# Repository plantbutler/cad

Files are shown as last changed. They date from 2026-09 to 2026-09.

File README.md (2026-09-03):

# plantbutler / cad

Everything physical about Plant Butler, reproducible from source: OpenSCAD parts, the KiCad
wiring diagram, the bill of materials and the bench notes.

- [`manifold/`](manifold/README.md) — the watering manifold: a lead screw moves a magnet cart
  over five ball gates on O-ring seats. Parametric OpenSCAD, ten printed parts, `make stl` for
  the print files. The FreeCAD design it replaces is kept in `manifold/reference/`.
- [`wiring/`](wiring/README.md) — how the bench is wired: four drawings (overview, pump
  switching, sensor bus, power), the pin map with connectors and wire colours, the parts to
  verify, and the bring-up order. Generated from `wiring/nets.py` by `make -C wiring`.

What comes next and in which order is in the [plan](https://github.com/plantbutler/plan); the
decisions it is built on are in the
[umbrella](https://github.com/plantbutler/plantbutler/blob/main/DECISIONS.md).

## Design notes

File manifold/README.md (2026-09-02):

# Plant Butler manifold v3

A parametric OpenSCAD (2021.01) model of the watering manifold: one water gallery with
`n_gates` outlets, each closed by an 8 mm steel ball resting on an O-ring, opened by a magnet
that a lead screw parks over the gate. It is a rebuild of the FreeCAD assembly `valveV2`
(`reference/`) with the inverted-nail plungers replaced by ball gates, every dimension derived
from `params.scad`, and every part printable flat with no supports.

Water enters through the inlet barb at the back, fills the gallery and leaves only through a
gate whose ball is lifted. A cart rides on the lid top, pushed along the manifold by an M3
threaded rod through a nut trapped in one of its ears; the rod turns in the servo holder at
the front and the screw holder at the back, driven by an SG90 through two spur gears outboard
of the servo holder. The magnet in the cart floor rides on the lid: parked over a gate it
lifts that ball off its O-ring and water flows under the ball into the outlet barb. The pump
is off while the cart moves (firmware). Home is the cart resting on the threadless front of
the rod against a spring.

Printed parts: `main_body`, `lid`, `outlet_barb` (one per gate), `end_cap`, `inlet_cap`,
`servo_holder`, `screw_holder`, `cart`, `servo_gear`, `screw_gear`. Hardware: 440C balls,
O-rings, a ø6×3 magnet, an M3 threaded rod, M3 nuts and washers, an SG90, M2 screws, a small
compression spring.

## Frame

X across the width (0..`W`), Y up (0 = outside floor of the main body), Z along the manifold;
the servo end is the front (−Z), the inlet end the back (+Z). Gate `i` (0-based) is centred at
`gate_z(i) = i·pitch + gate_len/2` — 9, 31, 53, 75, 97 with the defaults. Every part module
builds its part in this frame; `<part>_print()` lays it on z = 0 for export;
`<part>_size()` returns its [x, y, z] extents. `assembly.scad` only turns the whole scene by
`screen_rot` for the screen, so Y is up in the pictures.

## How a gate works

The ball (ø `ball_d`) rests on an O-ring of inner diameter `oring_id` and cross-section
`oring_cs`, whose tube centre-line has radius `r_o = (oring_id + oring_cs)/2`; ball and tube
touch when their centres are `Rb = ball_d/2 + oring_cs/2` apart, so the seated ball centre sits
`sqrt(Rb² − r_o²)` above the ring's centre plane `y_ring`. Lifting the ball opens a
frustum-shaped throat between the ring and the ball, of area `π·r_o·(1 + k/D)·(D − Rb)` with
`k = ball_d/2 − oring_cs/2` and `D` the new centre distance; setting that equal to
`lift_factor` × the outlet bore area gives a quadratic in `D`, `lift` follows from it, and the
gallery height `inner_h` is the smallest number of layers that lets the lifted ball touch the
lid lip.

The O-ring sits in a counterbore ø `groove_od` × `groove_d` in the top of a seat boss on the
floor, its inner diameter at the edge of the outlet hole; the counterbore is `groove_d` deep so
the ball touches rubber, never the step. A cage tube on the lid (ø `cage_bore` inside) reaches
`cage_below_equator` below the seated ball's centre, so the ball cannot leave its seat sideways,
and stops `cage_window_h` above the boss so water can enter under it.

## Parameters (`params.scad`)

Everything else is derived; the derivations are guarded by asserts that fail with a message.

| name | default | why |
|---|---|---|
| `line_w`, `layer_h` | 0.4, 0.2 | printer: thin frames are multiples of `line_w`, heights that must land on a layer round up to `layer_h` |
| `fn_round`, `fn_small` | 64, 32 | `$fn` for sealing/running features and for small holes |
| `n_gates` | 5 | outputs |
| `gate_len`, `joint_len` | 18, 4 | gallery length per gate; lap joint length [v2] |
| `wall` | 1.6 | every wall = 4 perimeters; lap joints split it into two half-skins |
| `inner_w` | 18 | gallery width [v2] |
| `extra_len` | 10 | end cap cavity in front of the first gate, room for the water to turn [v2] |
| `joint_clear` | 0.15 | per-side clearance on lap joints and the lid lip (v2 had 0: does not fit FDM) |
| `lip_chamfer` | 1.6 | 45° fillets under the lid lip [v2 internal_chamfer] |
| `gallery_chamfer` | 1.6 | 45° fillets along the gallery's inner floor/wall corners, between the lap joints [v2 large_Chamfer]; asserted clear of the seat boss |
| `ball_d`, `outlet_id` | 8, 4 | 440C ball; outlet hole through the floor |
| `oring_id`, `oring_cs` | 4, 1.5 | O-ring; its ID sits at the outlet hole edge |
| `groove_depth_ratio` | 0.75 | groove depth as a fraction of the cross-section: the ball must touch the ring, not the step |
| `groove_clear` | 0.2 | radial slack on the counterbore so the ring drops in |
| `seat_floor_min`, `seat_boss_wall` | 1.2, 1.2 | material under the groove (6 layers) and around it (3 perimeters) |
| `lift_factor` | 2 | throat area under the lifted ball = `lift_factor` × outlet bore area |
| `cage_clear`, `cage_wall` | 0.4, 1.2 | radial slack ball ↔ cage; cage wall = 3 perimeters |
| `cage_below_equator` | 1.5 | how far the cage reaches below the seated ball centre |
| `cage_window_min`, `cage_side_gap` | 1.5, 1.0 | minimum gap cage ↔ boss for the water; minimum gap cage ↔ gallery wall |
| `lid_slot_depth` | 0 | optional magnet groove along the lid top (0 = flat, as v2) |
| `mag_d`, `mag_h`, `mag_clear`, `mag_margin` | 6, 3, 0.1, 1.0 | ø6×3 magnet, press-fit hole, floor left each side of it |
| `ear_h`, `ear_top_w`, `ear_base_inset` | 7, 7.2, 1.6 | cart ears: height, top width (swallows the nut slot + 2 perimeters each side) [v2 5], root inset from the floor edge |
| `screw_h` | 5.5 | rod axis above the lid top [v2] |
| `screw_d`, `screw_hole_d` | 3, 3.2 | M3 rod and its clearance hole |
| `nut_af`, `nut_clear`, `nut_t` | 5.5, 0.1, 2.4 | M3 nut across flats, slot clearance, thickness |
| `gear_module`, `servo_teeth`, `screw_teeth`, `gear_t` | 0.75, 20, 20, 4 | two identical gears, OD 16.5, centre distance 15 [gears.FCStd] |
| `gear_backlash`, `pressure_angle` | 0.1, 20 | taken off each tooth thickness so printed gears do not bind |
| `servo_spline_d`, `servo_spline_depth`, `servo_screw_d` | 4.8, 3, 2.2 | SG90 21T spline press-fit pocket; horn screw clearance |
| `gear_gap` | 0.5 | servo body top to gear face |
| `servo_win` | [22.6, 11.6] | window through the plate for the SG90 body (fits Jacopo's servo; measure yours) |
| `servo_shaft_from_end` | 6 | shaft axis from the +X end of the body |
| `servo_tab_spacing`, `servo_tab_hole_d`, `servo_boss_d`, `servo_screw_engage` | 27.5, 2.5, 4.1, 8.5 | mounting tabs; bosses on the body side; plate + boss = M2 engagement |
| `servo_frame_w`, `servo_margin` | 0.8, 3 | guide frame around the window; plate outline margin |
| `holder_r_top`, `holder_r_bot` | 6, 10 | plate outline rounds |
| `rib_h`, `rib_depth`, `gusset` | 8, 8, 7 | ribs on the plate's body side and their 45° gusset |
| `sg90_tab_t`, `sg90_top_h`, `sg90_spline_len`, `sg90_body_len`, `sg90_flange_len` | 2.5, 4.3, 3.2, 22.7, 32.2 | SG90 geometry: tab thickness, tab top → case top, spline, case height, tabs tip to tip (the last two for the assembly ghost only) |
| `sh_side_h`, `sh_foot_len`, `sh_foot_chamfer` | 4, 2, 2 | screw holder plate height at the sides, feet toward the body [v2 4: the cart could not reach the last gate], chamfer on the feet's free corner [v2 3 on 4 mm feet], asserted no larger than the foot |
| `outlet_barb`, `outlet_barb_prof`, `outlet_flange` | [4, 6, 7, 14], [3, 5], [10, 4] | bore, shank OD, ridge OD, length; ridge taper length, tip OD; base cone [v2 connector] |
| `inlet_barb`, `inlet_barb_prof` | [8, 10, 12.5, 22], [5, 9.5] | the same for the inlet [v2 connector_8mm] |
| `barb_steep`, `barb_ridges`, `barb_ridge_gap` | 50, 2, 2 | ridge face angle from the axis, number of ridges, shank between taper end and next crest [v2] |
| `end_cap_outlet` | false | an inlet barb through the end cap's front wall for daisy-chaining (modelled; it clashes with the screw gear, the assembly shows it) |
| `washer_od`, `washer_t` | 7, 0.5 | M3 washers on the servo plate (ghosts only) |
| `spring_od`, `spring_wire`, `spring_len`, `spring_turns` | 5.5, 0.5, 10, 6 | the spring on the threadless front of the rod (ghost only) |

## Derived numbers with the defaults (`make report`)

```
pitch = 22, W = 21.2
groove_d = 1.2, groove_od = 7.2, seat_land = 0, seat_boss_h = 0.8, seat_boss_d = 9.6
r_o = 2.75, y_floor = 1.6, y_boss = 2.4, y_ring = 1.95, Rb = 4.75, ball_y = 5.82
k = 3.25, c = 2.91, b = -4.41, D = 6.71, lift = 2.25, throat_area = 25.13
inner_h = 10.6, top_y = 13.8, body_h = 13, gal_y = 6.9
cage_bore = 8.8, cage_od = 11.2, cage_bottom_y = 4.32, cage_window_h = 1.92, seated_gap = 3.98
body_z0 = -4, body_z1 = 110, z_cap0 = -15.6, z_plate1 = -14
gate_z = [9, 31, 53, 75, 97]
screw_y = 19.3, gear_cd = 15, gear_od = 16.5, servo_y = 34.3, win_cx = 5.3, tab_x = [-8.45, 19.05]
gear_z1 = -22.9, gear_z0 = -26.9, rod_z = [-30.3, 113.4], nut_ac = 6.47
ear_t = 4.1, cart_len = 16.3, cart_w = 17.2, cart_top = 23.8
sh_top = 22.5, sh_flat = 3.2
```

Part extents [x, y, z] in the frame: main_body [21.2, 13, 114], lid [21.2, 9.48, 114],
outlet_barb [10, 14, 10], end_cap [21.2, 13.8, 15.6], inlet_cap [19.3, 12.5, 22],
servo_holder [32.65, 29.3, 9.6], screw_holder [21.2, 8.7, 3.6], cart [17.2, 10, 16.3],
servo_gear and screw_gear [16.5, 16.5, 4].

## What to measure on the bench

- **`seated_gap` = 3.98 mm**: magnet face (the lid top) to the top of the seated ball. It
  already includes the 1.6 mm (= `wall`) of lid plate + lip that sits on the centreline between
  magnet and ball, plus `lift` and the layer rounding — see the `seated_gap` line in
  `params.scad`; nothing is to be added to it. The magnet has to lift the ball across this gap
  against the ball's weight and the water pressure on the seat (π·r_o² ≈ 24 mm²: 0.23 N per
  metre of head). Measure the pull of the ø6×3 magnet on the ball through a non-magnetic spacer
  at 3.98 mm (ball seated) and at 3.98 − `lift` = 1.73 mm (ball lifted) with a scale; if it is
  marginal, raise `groove_depth_ratio` or lower `lift_factor` (both bring the ball closer)
  before changing the magnet.
- **`cage_window_h` = 1.92 mm**: the gap between the cage bottom and the seat boss on the printed
  lid + body; a feeler must pass all round, or the water cannot reach the seat.
- **Magnet release**: with the cart parked one gate away the ball must drop; the display rule
  in the assembly (a ball lifts when its gate centre is within `mag_d/2` of the magnet axis) is
  a guess, not a measurement.
- **Home vs gate 0**: the cart can go no further forward than the servo holder ribs
  (`z_plate1 + rib_depth`), which puts the magnet axis `z_plate1 + rib_depth + cart_len/2 - gate_z(0)`
  = 6.85 mm before gate 0 (defaults): more than `mag_d/2`, so a cart parked there holds no ball up.
  The rod's threadless length and the spring decide where home really is: make it end before the
  magnet gets within `mag_d/2` of gate 0, or gate 0 dribbles at rest. `spring_len` is a ghost.
- **Lap skins**: the body's front side skins are `wall/2 - joint_clear` = 0.65 mm, one Arachne line
  on the P2S; they are located by the end cap's 0.8 mm skins and glued. If a print comes out
  ragged there, raise `wall` to 2.0 (everything above it re-derives) rather than thinning the ring.
- **Seal**: fill to 1 m of head; the lid lip glue line and the outlet barbs are the seams to
  watch (see below).

## Assembly and sealing

O-rings into the counterbores, balls onto them, lid lowered so the cages capture the balls;
lid, end cap, inlet cap, outlet barbs and screw holder are **bonded** (CA or epoxy for
PLA/PETG): the lap joints (`joint_clear`) and the plate/wall butt joints are glue joints with a
bead of sealant along the lid lip. The lid must resist ≈ 2 kgf per metre of pump head
(9.8 kPa × 18 × 110 mm² ≈ 19 N at 1 m), so no clips or bare press fits. The lid top stays
flat for the cart. Nut into the cart slot, cart onto the lid, rod through screw holder → cart →
servo holder, spring on the threadless front, nuts and washers each side of the servo plate,
screw gear with its nut outboard, servo gear pressed on the spline and held by the horn
screw, SG90 screwed to the plate from the front.

## Printing (P2S, PLA/PETG, 0.2 mm layers, 0.4 nozzle)

Flat face on the bed, no supports, overhangs ≤ 45°, bridges ≤ 8 mm. `make stl` exports
every part in this orientation.

| part | face on bed | check |
|---|---|---|
| main_body | outside floor (y = 0), flat over the full length | walls and seat bosses vertical, counterbores open up, gallery fillets 45° |
| lid | plate top (y = top_y) | cages stand up, lip fillets are 45° |
| outlet_barb | flange (y = 0 face) | ridge steep faces are 0.5 mm steps |
| end_cap | front wall (z = z_cap0) | cavity and ring open up (with `end_cap_outlet` it is turned over: barb up, front wall bridging) |
| inlet_cap | plug front face (z = body_z1 − joint_len) | barb vertical |
| servo_holder | plate front face (z = z_cap0) | frame, bosses, ribs extrude up; gusset 45° |
| screw_holder | plate back face (z = body_z1), flipped | feet up |
| cart | floor bottom (y = top_y) | ears up, nut slot opens up |
| gears | the pocket-free face | pockets open up |

## Rendering and checking

OpenSCAD 2021.01 at `/Applications/OpenSCAD-2021.01.app/Contents/MacOS/OpenSCAD` (`OPENSCAD=`
overrides it).

```
make            # stl + png
make stl        # build/stl/<part>.stl, each verified to be one solid (Simple: yes, Volumes: 2)
make png        # renders/<part>.png and renders/assembly_<view>.png
make check      # params, every part and the assembly with the defaults and with
                # lift_factor=1, lift_factor=3, ball_d=10, oring_cs=2, n_gates=3, inner_w=20, gear_module=1
make report     # echo every derived number
```

`assembly.scad` takes `-D 'view="iso|length|gate|between|cart|front"'` (sections: keep
x < W/2; z < gate_z(1); z < the joint after gate 1; z < the cart's middle; z < the servo plate's
back face), `-D explode=0..20` (parts move along their assembly directions) and `-D cart_z=`
(the cart's front face; the ball under the magnet is drawn lifted). Each view renders with the
camera the file echoes (`ECHO: camera = "eye,center"`), because `--viewall` fits the uncut
leaves of a sectioned preview. Part files take `-D for_print=true` for the print orientation
and any parameter as `-D name=value`; the assembly `use`s the parts, so a `-D` on it does not
reach them — `make check` substitutes into a copied `params.scad` instead. The assembly pass
runs the asserts of `params.scad` (`include`d) and those inside each part's module — every
part keeps its asserts there because a `use`d file's top-level statements never execute — so
a part-file top-level statement is only exercised by `make check`'s per-part STL exports or by
rendering that part on its own, not by `assembly.scad` in the GUI or by `make png`.

## What differs from valveV2 and why

- Ball gates on O-ring seats replace the inverted-nail plungers: a seat boss with a counterbore
  per gate on the body, cage tubes on the lid instead of plunger guides. The gallery height is
  derived from ball + lift: `top_y` 13.8 (v2 13.2), `body_h` 13.0 (v2 12.4).
- `joint_clear` 0.15 mm per side on every lap joint and the lid lip (v2: 0, does not fit FDM).
- The body's front lap has a full-thickness floor on the bed and only the inner half of each
  side wall; the end cap's ring is just two side skins, no floor skin and no top bar (v2's
  0.8 mm floor skin there floated above the bed); the lid plate extends over the front lap,
  narrowed by `joint_clear`, and closes the ring's top, so the lip and its fillets lie on the
  bed over their whole length instead of hanging 4 mm past the plate.
- The cart's drive nut drops into a top-loading slot in the front ear and cannot turn or move
  axially (v2's through-hex let the rod push the nut out); `ear_top_w` 7.2 (v2 5) to swallow
  it, ears rooted 1.6 mm in from the floor edge, `cart_w` = `inner_w` − 2·`line_w`.
- Screw holder feet 2 mm long (v2 4): with the longer cart the magnet could not reach gate 5.
  Their chamfer is 2 (v2 3): a 45° chamfer cannot exceed the foot, an assert says so. Apex
  half-width 3.2 = hole radius + wall (v2 hard-coded 3.1).
- Gears: same 20T m0.75 pair at 15 mm centres; their plane is derived from the SG90 (tab
  thickness, tab top → case top, `gear_gap`), giving z −26.9..−22.9.
- Outlet barb: the valley between the two ridges returns to the ø6 shank (v2 ø5.5); everything
  else on both barbs matches v2's profiles.
- The body's 1.6 mm fillets along the inner floor/wall corners (`gallery_chamfer`, v2
  large_Chamfer) stop at the lap joints; v2 ran them through the front lap into the end cap's
  square cavity.
- Not reproduced: v2's 0.4 mm lead-in on the ring's inner edges and the 0.4 mm chamfer on the
  wall tops.
- Everything is a parameter or derived from one; a set that cannot be built fails an assert
  with a message.

## Reference files

- `reference/valveV2.FCStd`, `reference/valveV2.step` — the FreeCAD assembly this reproduces.
  Every sketch, constraint and feature was dumped from the FCStd and each body meshed in the
  assembly frame to overlay against these parts; the numbers in [brackets] in `params.scad`
  are v2's.
- `renders/` — one preview per part and the six assembly views, regenerated by `make png`
  (kept under 150 KB each).
- `lib/README.md` — the shared helpers (shapes, barb, O-ring, involute gear).

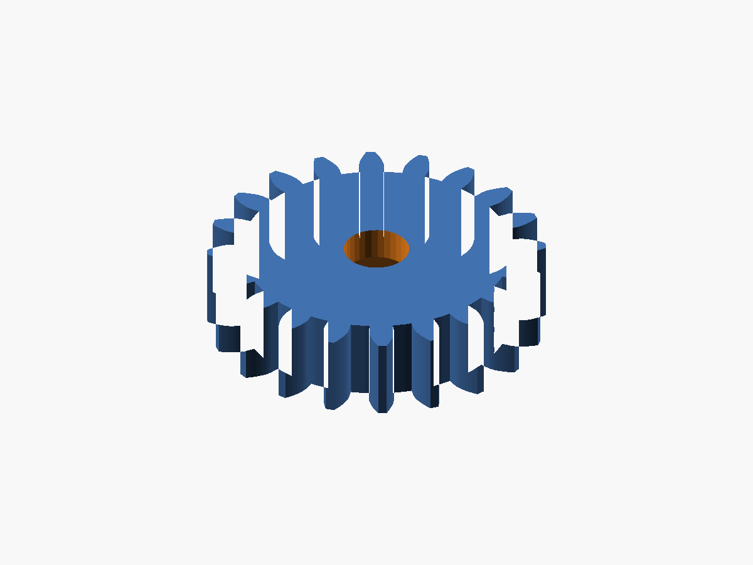
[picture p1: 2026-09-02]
manifold/renders/screw_gear.png

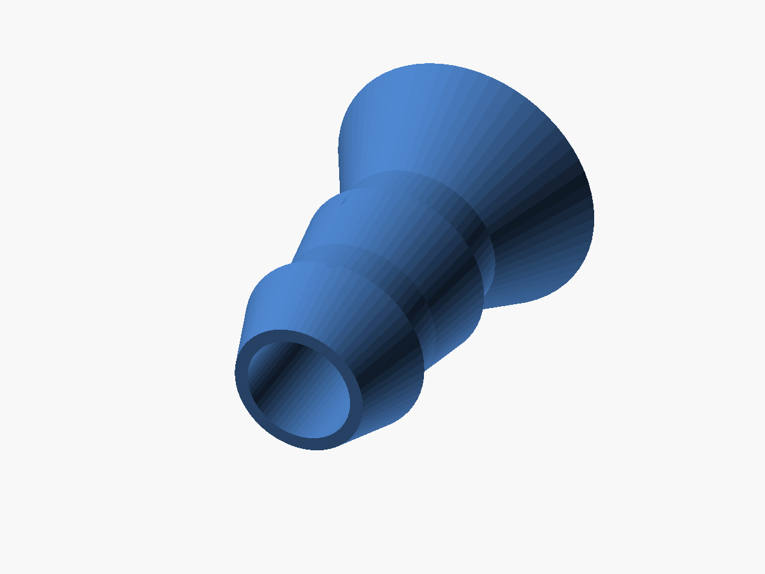
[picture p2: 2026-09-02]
manifold/renders/outlet_barb.png

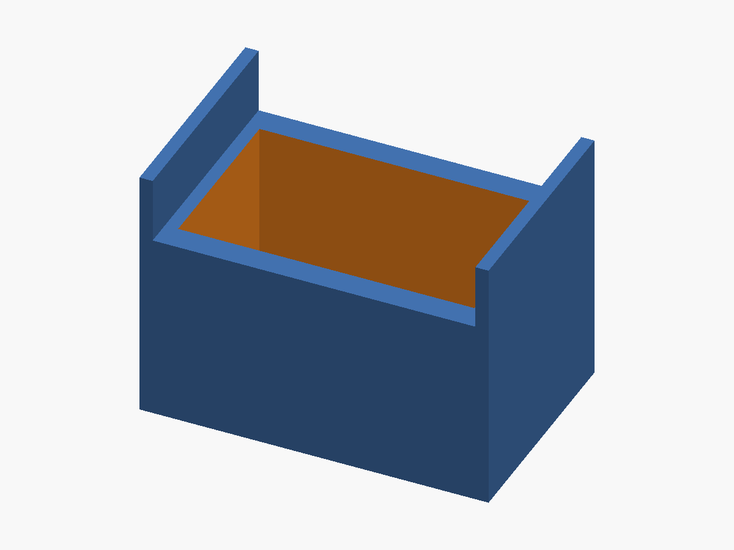
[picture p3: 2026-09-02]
manifold/renders/end_cap.png

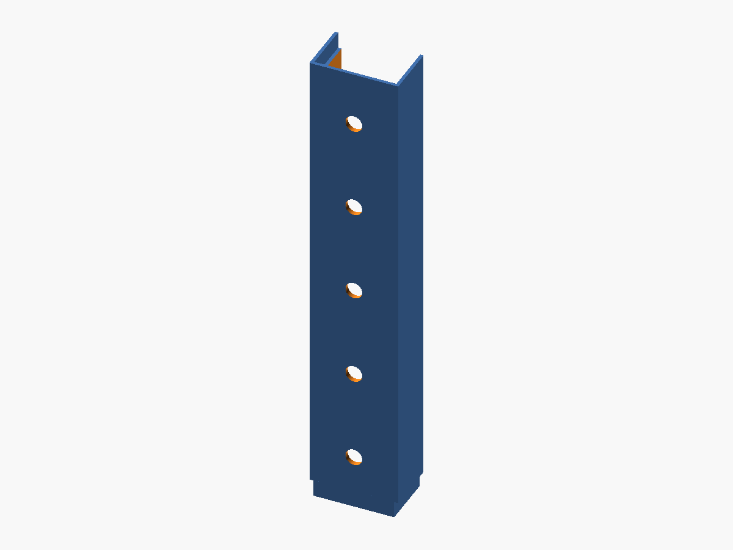
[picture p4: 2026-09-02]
manifold/renders/main_body.png

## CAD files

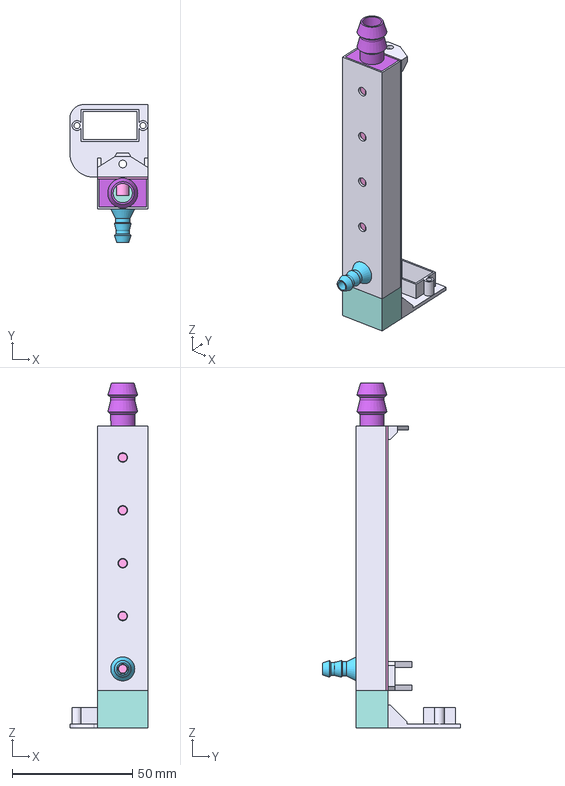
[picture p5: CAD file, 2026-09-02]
manifold/reference/valveV2.step
32.6 x 57.5 x 143.6 mm
main_body
lid
connector
end_cap
in_cap
servo_holder
screw_holder
cart

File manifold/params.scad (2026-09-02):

// Plant Butler manifold v3 — the parameter contract. Every file `include`s this and every
// dimension anywhere is an expression of these names; nothing is typed twice.
//
// Frame: X across the width (0..W), Y up (0 = outside bottom of the main body), Z along the
// manifold; the servo end is the front (−Z), the inlet end the back (+Z).
// Numbers in [brackets] are valveV2's (reference/valveV2.FCStd).

// ---- printer -------------------------------------------------------------------------------
line_w  = 0.4;    // extrusion width: thin frames and skins are multiples of it
layer_h = 0.2;    // heights that must land on a layer are rounded UP to a multiple of it
fn_round = 64;    // $fn for anything that seals or runs: bores, barbs, cages, gears, balls
fn_small = 32;    // $fn for screw holes, bosses and other small round features

// ---- layout [v2] ---------------------------------------------------------------------------
n_gates   = 5;      // number of outputs
gate_len  = 18;     // gallery length per gate [v2 innerBoxLength]
joint_len = 4;      // lap joint length between body, lid, caps [v2 boxConnections]
wall      = 1.6;    // every wall = 4 perimeters; lap joints split it into two half-skins
inner_w   = 18;     // gallery width [v2 innerBoxWidth]
extra_len = 10;     // end cap cavity in front of the body: room for the water to turn [v2 extraLength]
joint_clear = 0.15;       // per-side clearance on lap joints and the lid lip (v2 had 0: does not fit FDM)
lip_chamfer = 4*line_w;   // 45° fillets under the lid lip [v2 internal_chamfer 1.6]
gallery_chamfer = 4*line_w;   // 45° fillets along the gallery's inner floor/wall corners [v2 large_Chamfer 1.6]: 45° so it prints floor-down

// ---- ball gate (new in v3) ------------------------------------------------------------------
ball_d    = 8;      // 440C ball
outlet_id = 4;      // outlet hole through the floor
oring_id  = 4;      // O-ring inner diameter: its ID sits at the outlet hole edge
oring_cs  = 1.5;    // O-ring cross-section
groove_depth_ratio = 0.75;  // groove depth as a fraction of the cross-section: the ball must touch the ring, not the step
groove_clear   = 0.2;       // radial slack on the counterbore so the ring drops in
seat_floor_min = 1.2;       // material left under the groove: 6 layers
seat_boss_wall = 1.2;       // material around the groove: 3 perimeters
lift_factor = 2;            // throat area under the lifted ball = lift_factor × outlet bore area
cage_clear = 0.4;           // radial slack ball ↔ cage bore, so a rough print cannot pinch the ball
cage_wall  = 1.2;           // cage tube wall: 3 perimeters
cage_below_equator = 1.5;   // cage reaches this far below the seated ball centre: it cannot escape sideways
cage_window_min = 1.5;      // minimum gap cage bottom ↔ seat boss for the water to enter
cage_side_gap  = 1.0;       // minimum gap cage OD ↔ gallery wall each side
lid_slot_depth = 0;         // optional groove along the lid top for the magnet (0 = flat top as v2)

// ---- magnet and cart [v2 magDiameter 6.1 was the hole] -------------------------------------
mag_d = 6;  mag_h = 3;      // ø6×3 disc magnet
mag_clear  = 0.1;           // on the hole diameter: press fit
mag_margin = 1.0;           // floor material each side of the magnet hole
ear_h = 7;                  // ear height above the cart floor top
ear_top_w = 7.2;            // ear width at the top [v2 5]: must swallow the nut slot plus 2 perimeters each side
ear_base_inset = 4*line_w;  // ears root this far in from the floor edge [v2 1.6]

// ---- lead screw [v2] -----------------------------------------------------------------------
screw_h = 5.5;              // rod axis above the lid top
screw_d = 3;  screw_hole_d = 3.2;   // M3 rod and its clearance hole
nut_af = 5.5;  nut_clear = 0.1;  nut_t = 2.4;   // M3 nut across flats, slot clearance, thickness

// ---- gears [gears.FCStd: two identical, OD 16.5, 4 thick, centre distance 15] --------------
gear_module = 0.75;  servo_teeth = 20;  screw_teeth = 20;  gear_t = 4;
gear_backlash = 0.1;        // taken off each tooth thickness so printed gears do not bind
pressure_angle = 20;
servo_spline_d = 4.8;  servo_spline_depth = 3;   // SG90 21T spline: press-fit pocket in the servo gear
servo_screw_d = 2.2;        // horn screw clearance through the rest of the servo gear
gear_gap = 0.5;             // servo body top to gear face

// ---- SG90 [v2 servo_holder] ----------------------------------------------------------------
servo_win = [22.6, 11.6];   // window through the plate for the body, x × y (v2 fits Jacopo's servo; measure yours)
servo_shaft_from_end = 6;   // shaft axis 6 mm from the +X end of the body
servo_tab_spacing = 27.5;  servo_tab_hole_d = 2.5;   // mounting tab holes
servo_boss_d = 4.1;         // bosses around the tab holes on the body side [v2 servo_spacer]
servo_screw_engage = 8.5;   // plate + boss = M2 screw engagement [v2 8.5 − wall pad]
servo_frame_w = 2*line_w;   // guide frame around the window on the +Z side
servo_margin = 3;           // plate outline margin around window and tab holes
holder_r_top = 6;  holder_r_bot = 10;   // plate outline rounds, left top / left bottom
rib_h = 8;  rib_depth = 8;  gusset = 7; // ribs on the plate's body side and their 45° gusset
sg90_tab_t = 2.5;  sg90_top_h = 4.3;  sg90_spline_len = 3.2;   // tab thickness, tab top→body top, spline
sg90_body_len = 22.7;       // case height from its top (shaft side) down along the shaft axis: assembly ghost only
sg90_flange_len = 32.2;     // mounting tabs tip to tip: assembly ghost only

// ---- screw holder [v2] ---------------------------------------------------------------------
sh_side_h = 4;              // plate height at the sides above the lid
sh_foot_len = 2;            // feet toward the body [v2 4: the cart could not reach gate 5 with a longer cart]
sh_foot_chamfer = 2;        // chamfer on the feet's free corner [v2 3 on 4 mm feet: a 45° chamfer cannot exceed sh_foot_len]

// ---- barbs [v2 connector / connector_8mm profiles] -----------------------------------------
outlet_barb = [outlet_id, 6, 7, 14];   // bore, shank OD, ridge OD, length
outlet_barb_prof = [3, 5];             // ridge taper length, tip OD
outlet_flange = [10, 4];               // base cone ø10→shank over 4 mm (v2 exitSupport)
inlet_barb  = [8, 10, 12.5, 22];  inlet_barb_prof = [5, 9.5];
barb_steep = 50;            // ridge face angle from the axis on the flange side [v2 130° interior]
barb_ridges = 2;
barb_ridge_gap = 2;         // shank between one ridge's taper end and the next crest [v2: 2 in both sketches]
end_cap_outlet = false;     // true: an inlet_barb through the end cap's front wall for daisy-chaining

// ---- other non-printed hardware (assembly ghosts and the README only) -----------------------
washer_od = 7;  washer_t = 0.5;                     // M3 washers under the nuts on the servo plate
spring_od = 5.5;  spring_wire = 0.5;  spring_len = 10;  spring_turns = 6;   // compression spring on the threadless front of the rod: ID clears M3

// ============================================================================================
// Derived values. Guarded by asserts: a parameter set that cannot be built fails here with a
// message, never silently. num_tol absorbs floating point noise in ceil() and >= comparisons.
// ============================================================================================
num_tol = 1e-6;
function layers_up(h) = ceil(h/layer_h - num_tol)*layer_h;   // smallest multiple of layer_h >= h
function gate_z(i) = i*pitch + gate_len/2;                    // centre of gate i (0-based) [v2 9, 31, 53, 75, 97]
function gear_od(t) = gear_module*(t + 2);                     // tip diameter of a t-tooth gear

// -- layout
pitch = gate_len + joint_len;                                  // 22
W = inner_w + 2*wall;                                          // 21.2
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

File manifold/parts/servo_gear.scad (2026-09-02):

// parts/servo_gear.scad — the spur gear on the SG90 spline [gears.FCStd servo_gear].
//
// Axis Z on the servo shaft (W/2, servo_y), z∈[gear_z0, gear_z1] outboard of the servo
// holder. A ø`servo_spline_d` pocket `servo_spline_depth` deep from the +Z (servo) face takes
// the 21T spline as a press fit; the ø`servo_screw_d` hole through the rest passes the horn
// screw. The gear already carries its meshing phase: one tooth points at the screw gear (−Y),
// which has a gap there (screw_gear.scad) — the assembly places both as they are.

include <../params.scad>
use <../lib/gear.scad>
$fn = fn_round;
eps = 0.01;

sg_root_r = gear_root_r(servo_teeth, gear_module);   // hub material outside the pocket must stay a wall

// The asserts live inside the module, not at file top level: `use <servo_gear.scad>` (assembly.scad)
// imports modules, functions and variables but does not execute top-level statements, so a
// file-top assert would be silent in the assembly and only fire on a standalone render.
module servo_gear() {
    assert(servo_spline_depth < gear_t - num_tol, "servo_gear: spline pocket goes through the gear");
    assert(servo_spline_d/2 + wall <= sg_root_r + num_tol, "servo_gear: less than a wall between the spline pocket and the tooth roots");
    assert(servo_screw_d < servo_spline_d, "servo_gear: horn screw hole wider than the spline pocket");
    translate([W/2, servo_y, gear_z0]) difference() {
        // gear_2d puts a tooth on +X: turned so it points at the screw gear below (−Y)
        rotate([0, 0, -90]) spur_gear(servo_teeth, gear_module, gear_t, pressure_angle, gear_backlash);
        translate([0, 0, gear_t - servo_spline_depth]) cylinder(d=servo_spline_d, h=servo_spline_depth + eps);
        translate([0, 0, -eps]) cylinder(d=servo_screw_d, h=gear_t + 2*eps, $fn=fn_small);
    }
}

// Print: the pocket-free −Z face (z = gear_z0) on the bed, spline pocket opening up.
module servo_gear_print() { translate([0, 0, -gear_z0]) servo_gear(); }

function servo_gear_size() = [gear_od(servo_teeth), gear_od(servo_teeth), gear_t];

for_print = false;
if (is_undef(ASSEMBLY)) {
    echo(servo_gear_size=servo_gear_size(), sg_root_r=sg_root_r, pitch_r=gear_pitch_r(servo_teeth, gear_module));
    if (for_print) servo_gear_print(); else servo_gear();
}

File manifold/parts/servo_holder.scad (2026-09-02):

// parts/servo_holder.scad — the front plate that carries the SG90 and the front rod bearing
// [v2 Body007: sketches back_plate, supports, servo_spacer].
//
// A plate `wall` thick perpendicular to Z at z∈[z_cap0, z_plate1], its front face flush with
// the end cap's front face, standing on the end cap top (y = top_y). The outline is derived
// from the servo window: `servo_margin` past the left tab hole and above the window, the
// right edge flush with the body at x = W, two rounds on the left corners. On the body (+Z)
// side: a `servo_frame_w` guide frame around the window and ø`servo_boss_d` bosses on the tab
// holes, both `servo_screw_engage − wall` tall (plate + boss = M2 engagement), and two ribs
// on the end cap's side walls with a 45° gusset on the free top corner (v2 Chamfer007: the rib
// keeps its full height for rib_depth − gusset, then falls to rib_h − gusset at the free end).
// The SG90 mounts from the front: tabs on the −Z face, body through the window toward +Z,
// shaft toward −Z into the gears at z∈[gear_z0, gear_z1].

include <../params.scad>
use <../lib/shapes.scad>
$fn = fn_round;
eps = 0.01;

// ---- outline in the plate plane (x, y) ---------------------------------------------------
svh_x0 = tab_x[0] - servo_margin;                  // left edge: margin past the left tab hole [v2 −11.45]
svh_x1 = W;                                        // right edge flush with the body's side
svh_y0 = top_y;                                    // stands on the end cap top
svh_y1 = servo_y + servo_win.y/2 + servo_margin;   // margin above the window [v2 43.5]
svh_boss_h = servo_screw_engage - wall;            // frame and boss height: plate + boss = screw engagement [v2 6.9]
svh_depth = wall + max(rib_depth, svh_boss_h);     // total extent along Z from the front face
svh_win = [win_cx - servo_win.x/2, win_cx + servo_win.x/2, servo_y - servo_win.y/2, servo_y + servo_win.y/2];   // window x0, x1, y0, y1
svh_r = max(holder_r_top, holder_r_bot);           // the outline's rectangle starts past the larger round

// 2D plate outline: the hull of the two left rounds and the rectangle to the right of them.
// Both rounds touch x = svh_x0, so the hull's left edge is the straight line between them.
module servo_holder_outline() {
    hull() {
        translate([svh_x0 + holder_r_top, svh_y1 - holder_r_top]) circle(r=holder_r_top);
        translate([svh_x0 + holder_r_bot, svh_y0 + holder_r_bot]) circle(r=holder_r_bot);
        translate([svh_x0 + svh_r, svh_y0]) square([svh_x1 - svh_x0 - svh_r, svh_y1 - svh_y0]);
    }
}

// One rib on the plate's body side, x∈[0, wall]: full height rib_h for rib_depth − gusset,
// then a 45° gusset down to rib_h − gusset at the free end. Profile drawn in (y, z), extruded
// along +X (rotate([90,0,90]) maps 2D (u, v) and the extrusion w onto (w, u, v)).
module servo_holder_rib() {
    rotate([90, 0, 90]) linear_extrude(wall)
        polygon([[svh_y0, z_plate1], [svh_y0 + rib_h, z_plate1],
                 [svh_y0 + rib_h, z_plate1 + rib_depth - gusset],
                 [svh_y0 + rib_h - gusset, z_plate1 + rib_depth],
                 [svh_y0, z_plate1 + rib_depth]]);
}

// The asserts live inside the module, not at file top level: `use <servo_holder.scad>` (assembly.scad)
// imports modules, functions and variables but does not execute top-level statements, so a
// file-top assert would be silent in the assembly and only fire on a standalone render.
module servo_holder() {
    assert(holder_r_top + holder_r_bot <= svh_y1 - svh_y0 + num_tol, "servo_holder: the two left rounds overlap: lower holder_r_top/holder_r_bot");
    assert(max(holder_r_top, holder_r_bot) <= svh_x1 - svh_x0 + num_tol, "servo_holder: a left round is wider than the plate");
    assert(tab_x[1] + servo_boss_d/2 <= svh_x1 + num_tol, "servo_holder: the right tab boss sticks out past the plate edge x = W");
    assert(svh_win[1] + servo_frame_w <= svh_x1 + num_tol, "servo_holder: the window frame sticks out past the plate edge x = W");
    assert(screw_y + screw_hole_d/2 < svh_win[2] - servo_frame_w - num_tol, "servo_holder: rod hole runs into the window frame: gear_cd too small");
    assert(top_y + rib_h <= svh_win[2] - servo_frame_w + num_tol, "servo_holder: ribs reach the window frame");
    assert(gusset <= min(rib_h, rib_depth) + num_tol, "servo_holder: gusset larger than the rib");
    assert(servo_boss_d > servo_tab_hole_d + num_tol, "servo_holder: tab boss no wider than its hole");
    difference() {
        union() {
            translate([0, 0, z_cap0]) linear_extrude(wall) servo_holder_outline();
            // guide frame and tab bosses on the body side (v2 servo_spacer: one padded sketch).
            // convexity is a preview hint only: a ring is not convex, so without it OpenCSG
            // previews show gaps in its far wall (the export is unaffected).
            translate([0, 0, z_plate1]) linear_extrude(svh_boss_h, convexity=4) {
                translate([win_cx, servo_y]) square(servo_win + 2*servo_frame_w*[1, 1], center=true);
                for (x = tab_x) translate([x, servo_y]) circle(d=servo_boss_d, $fn=fn_small);
            }
            for (x = [0, W - wall]) translate([x, 0, 0]) servo_holder_rib();
        }
        // window for the servo body, through plate and frame
        translate([win_cx, servo_y, z_cap0 - eps]) linear_extrude(svh_depth + 2*eps) square(servo_win, center=true);
        // M2 tab screws through plate and bosses
        for (x = tab_x) translate([x, servo_y, z_cap0 - eps]) cylinder(d=servo_tab_hole_d, h=svh_depth + 2*eps, $fn=fn_small);
        // lead screw
        translate([W/2, screw_y, z_cap0 - eps]) cylinder(d=screw_hole_d, h=svh_depth + 2*eps, $fn=fn_small);
    }
}

// Print: plate front face (z = z_cap0) on the bed; frame, bosses and ribs extrude up, the
// gusset is a 45° overhang.
module servo_holder_print() { translate([0, 0, -z_cap0]) servo_holder(); }

function servo_holder_size() = [svh_x1 - svh_x0, svh_y1 - svh_y0, svh_depth];

for_print = false;
if (is_undef(ASSEMBLY)) {
    echo(servo_holder_size=servo_holder_size(), svh_x0=svh_x0, svh_y1=svh_y1, svh_win=svh_win, svh_boss_h=svh_boss_h);
    if (for_print) servo_holder_print(); else servo_holder();
}

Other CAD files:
manifold/assembly.scad
manifold/parts/cart.scad
manifold/parts/end_cap.scad
manifold/parts/inlet_cap.scad
manifold/parts/lid.scad
manifold/parts/main_body.scad
manifold/parts/outlet_barb.scad
manifold/parts/screw_gear.scad
manifold/parts/screw_holder.scad
manifold/reference/valveV2.FCStd

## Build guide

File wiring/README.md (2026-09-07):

<!-- generated by gen_readme.py from nets.py (2026-09-03); edit those, not this file -->
# Bench wiring: one manifold, five pots — 2026-09-03

Wiring drawings and pin map to bench ONE manifold (5 outlets) with 5 soil-moisture sensors, the Sensor Kit temperature and light modules, two I2C screens (OLED 0x3C, LCD1602 backpack 0x27), an analog mux and an I2C expander (so more manifolds bolt on without rewiring), the pump with its relay, the inline flow meter, the float hall, the manifold's servo and its screw and home halls. No PCB, no enclosure; KiCad comes once the bench has fixed the part choices. Source of truth: [`nets.py`](nets.py) (every wire, every table); the drawings and this file are generated from it.

## Binding rules

From the umbrella [DECISIONS.md](../../DECISIONS.md) #5 and #7 and the pitches "Bench rig" and "Don't flood the flat":

- The pump never touches a 5 V rail: 12 V through relay contacts, its return straight to the star (DECISIONS #7). The servo does run off the board's 5 V, which the R4's buck can carry — see Power.
- The pump is OFF unless the MCU actively asserts D6: an MCU in reset, a floating pin, a boot, an unpowered relay coil, a pulled jumper and a lost 12 V all mean pump off, in hardware.
- The float is a sense pin only (D5). There is no hardware interlock on this bench: read THE GAP under Pump driver before trusting the tank to a sketch.
- Failure direction is dry: NAS or WiFi down, unknown manifold position, float says empty -> no watering (DECISIONS #5). The backend decides when to water; the firmware only enforces caps.
- Firmware side of the bench: hall pulse counting on the lead screw plus a home hall (polled), flow sanity from the meter, sensors reported raw as (controller, channel) counts.
- 12 V loop on a soldered perfboard with screw terminals and >= 0.5 mm2 wire; breadboard and Dupont only for 5 V logic.

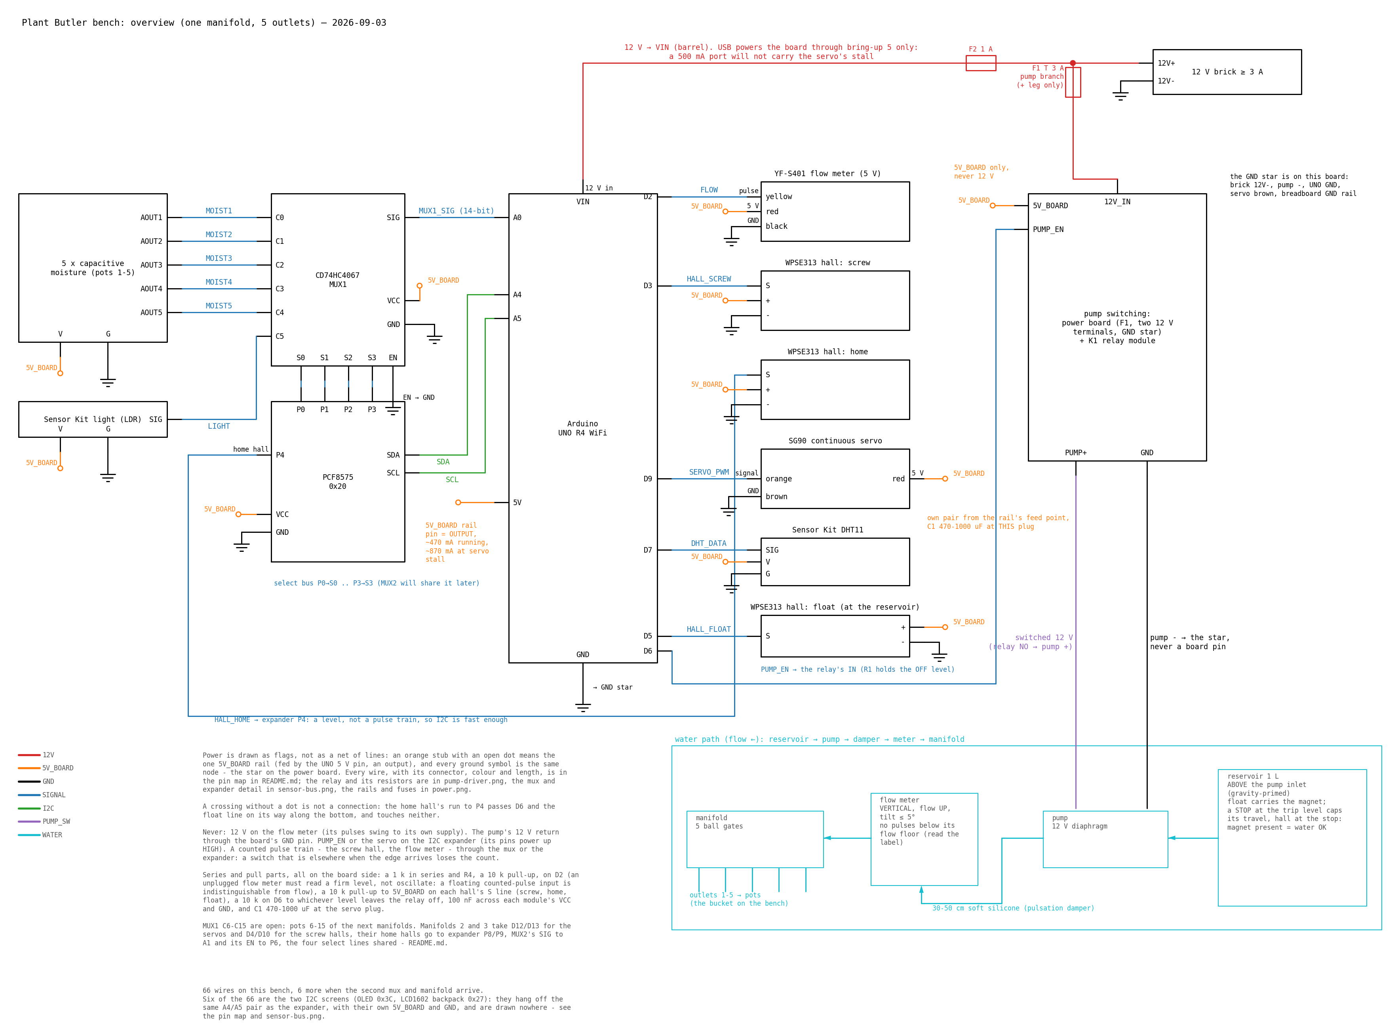
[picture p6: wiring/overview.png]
overview


*overview.png* — every used UNO pin labelled; one orange 5 V rail, and the pump's purple leg is 12 V out of the relay, never a GND; the screw hall and the flow meter land on interrupt pins while the home hall goes through the expander; the hydraulic strip along the bottom has the reservoir above the pump inlet.

## Pin map

Pins are inputs with pull-ups off at reset; D0/D1 stay free for serial; D6 gets its direction and the relay's OFF level in one PFS register write, because `pinMode(D6, OUTPUT)` on this core drives the pin LOW and would discard a level set before it (see the relay notes). `Wire` (A4/A5) is 5 V with no on-board pull-ups and carries the expander and both screens; the Qwiic connector is `Wire1` at 3.3 V and is not used.

| board pin | signal | module | module pin | series / pull | connector | wire colour | cable / note |
| --- | --- | --- | --- | --- | --- | --- | --- |
| D2 | FLOW | YF-S401 flow meter | yellow (pulse) | 1 k series at the board, 10 k pull-up to 5V_BOARD (R4) | 3-wire lead red / black / yellow | blue | <= 1 m; away from the servo lead; interrupt pin: pulses are counted, never muxed |
| D3 | HALL_SCREW | WPSE313 hall: screw pulse | S | 10 k pull-up to 5V_BOARD at the breadboard | 3-pin S / + (middle) / - | blue | <= 50 cm; hall fixed, magnet on the screw; interrupt pin: a missed edge is lost position |
| D5 | HALL_FLOAT | WPSE313 hall: float (tank) | S | 10 k pull-up to 5V_BOARD at the breadboard (R2) | 3-pin S / + (middle) / - plug: the one pulled in bring-up 5b | blue | to the reservoir, <= 1 m; direct pin, NOT the expander: shortest path for the safety input |
| D6 | PUMP_EN | 1-channel relay module K1 | IN | 10 k to the module's OFF level (R1): pull-down if active-HIGH, pull-up to 5V_BOARD if active-LOW | Dupont | blue | <= 30 cm; the jumper pulled in bring-up 4c |
| D7 | DHT_DATA | Sensor Kit temp/humidity (DHT11) | SIG |  | Grove 4-pin (VCC, GND, SIG, NC) | blue | Grove 20-50 cm; direct pin: us-level one-wire timing cannot cross a mux or the expander. Free if the kit has the DHT20 (I2C) |
| D9 | SERVO_PWM | SG90 continuous servo | orange (signal) |  | JR 3-pin brown / red / orange | blue | servo lead ~25 cm; direct pin: a servo needs its 50 Hz train unbroken (PCA9685 to expand) |
| A0 | MUX1_SIG | CD74HC4067 mux MUX1 | SIG |  | header / Dupont | blue | <= 20 cm; analog, 14-bit |
| A4 | SDA | PCF8575 I2C expander 0x20 | SDA | ONE set of pull-ups for the whole bus: 4.7 k to 5V_BOARD (VERIFY each module; remove the rest) | header / Dupont | green | <= 20 cm |
| A5 | SCL | PCF8575 I2C expander 0x20 | SCL | ONE set of pull-ups for the whole bus: 4.7 k to 5V_BOARD (VERIFY each module; remove the rest) | header / Dupont | green | <= 20 cm |
| A4/A5 | SDA + SCL | Sensor Kit OLED SSD1306 0x3C | SDA / SCL | ONE set of pull-ups for the whole bus: 4.7 k to 5V_BOARD (VERIFY each module; remove the rest) | Grove 4-pin (VCC, GND, SIG, NC) | green | Grove 20-50 cm; the same two wires as the expander: A4/A5 are a bus, not a pin each |
| A4/A5 | SDA + SCL | LCD1602 + PCF8574 backpack 0x27 | SDA / SCL | ONE set of pull-ups for the whole bus: 4.7 k to 5V_BOARD (VERIFY each module; remove the rest) | header / Dupont | green | <= 30 cm; shares the bus with the expander and the OLED |
| 5V | 5V_BOARD | 5V_BOARD rail (breadboard) | + |  | header / Dupont | orange | <= 20 cm; OUTPUT only, never fed. The board's buck gives 1.2 A total from VIN: see POWER_BUDGET |
| GND | GND | GND star (power board) | GND |  | screw terminal | black | <= 30 cm; the pump's 12 V return never passes here |
| VIN (barrel) | 12V | 12 V >= 3 A brick | 12V+ | 1 A fuse F2, + leg only | barrel 5.5/2.1 mm, centre + | red | the servo and the relay coil come out of this: do NOT run them on USB power (500 mA port) |
| A1 (later) | MUX2_SIG | CD74HC4067 mux MUX2 (later) | SIG |  |  | blue |  |

Free pins and what they are earmarked for:

| pin | use |
| --- | --- |
| D0 / D1 | serial: keep free |
| D4 | HALL_SCREW manifold 2 (later; freed when the home hall moved to the expander) |
| D8 | free |
| D10 | HALL_SCREW manifold 3 (later) |
| D11 | free |
| D12 | SERVO_PWM manifold 2 (later) |
| D13 | SERVO_PWM manifold 3 (later) |
| A1 | MUX2 SIG (later) |
| A2 | free (analog) |
| A3 | free (analog) |

Per manifold (manifold 1 is the bench):

| manifold | servo PWM | screw hall | home hall | mux SIG |
| --- | --- | --- | --- | --- |
| 1 (bench) | D9 | D3 | P4 (expander) | A0 (MUX1) |
| 2 (later) | D12 | D4 | P8 (expander) | A1 (MUX2) |
| 3 (later) | D13 | D10 | P9 (expander) | A1 (MUX2, C6-C15) |

What scales where, by signal type, not by habit: analog and slow (moisture, light) on the mux, 16 a piece; a level and slow (home hall, and the one float) on the expander or a spare pin; a counted pulse train (screw hall, flow meter) on an interrupt pin, because a mux is a switch and an edge missed while it sits on another channel is lost cart position. Past three manifolds, route the screw halls through a 74HC4051 into one interrupt pin (only one manifold moves at a time) and the servos onto a PCA9685 (16 channels of hardware PWM over I2C, its own 5 V supply) rather than spending a board pin each.

<details>
<summary>Every wire: 72 rows, 66 on the bench, 6 later (dashed on the drawings)</summary>

Module ids used below:

| id | module | status |
| --- | --- | --- |
| UNO | Arduino UNO R4 WiFi | in hand |
| PCF8575 | PCF8575 I2C expander 0x20 | in hand |
| MUX1 | CD74HC4067 mux MUX1 | in hand |
| MUX2 | CD74HC4067 mux MUX2 (later) | later |
| MOIST1 | moisture 1 (capacitive) | in hand |
| MOIST2 | moisture 2 (capacitive) | in hand |
| MOIST3 | moisture 3 (capacitive) | in hand |
| MOIST4 | moisture 4 (capacitive) | in hand |
| MOIST5 | moisture 5 (capacitive) | in hand |
| LDR | Sensor Kit light (LDR) | in hand |
| DHT | Sensor Kit temp/humidity (DHT11) | in hand |
| OLED | Sensor Kit OLED SSD1306 0x3C | in hand |
| LCD | LCD1602 + PCF8574 backpack 0x27 | in hand |
| SERVO | SG90 continuous servo | in hand |
| HALL_SCREW | WPSE313 hall: screw pulse | in hand |
| HALL_HOME | WPSE313 hall: home | in hand |
| HALL_FLOAT | WPSE313 hall: float (tank) | in hand |
| FLOW | YF-S401 flow meter | ASSUME |
| RELAY | 1-channel relay module K1 | in hand |
| PERFBOARD | power board: F1, 12 V terminals, GND star | bench |
| PUMP | 12 V diaphragm pump | ASSUME |
| BRICK | 12 V >= 3 A brick | ASSUME |
| RAIL5V | 5V_BOARD rail (breadboard) | bench |
| RAILGND | GND rail (breadboard) | bench |
| STAR | GND star (power board) | bench |

| from | pin | to | pin | net | colour | series / pull | connector | cable / note | when |
| --- | --- | --- | --- | --- | --- | --- | --- | --- | --- |
| UNO | D2 | FLOW | yellow (pulse) | SIGNAL | blue | 1 k series at the board, 10 k pull-up to 5V_BOARD (R4) | 3-wire lead red / black / yellow | <= 1 m; away from the servo lead; interrupt pin: pulses are counted, never muxed | bench |
| UNO | D3 | HALL_SCREW | S | SIGNAL | blue | 10 k pull-up to 5V_BOARD at the breadboard | 3-pin S / + (middle) / - | <= 50 cm; hall fixed, magnet on the screw; interrupt pin: a missed edge is lost position | bench |
| UNO | D5 | HALL_FLOAT | S | SIGNAL | blue | 10 k pull-up to 5V_BOARD at the breadboard (R2) | 3-pin S / + (middle) / - plug: the one pulled in bring-up 5b | to the reservoir, <= 1 m; direct pin, NOT the expander: shortest path for the safety input | bench |
| UNO | D6 | RELAY | IN | SIGNAL | blue | 10 k to the module's OFF level (R1): pull-down if active-HIGH, pull-up to 5V_BOARD if active-LOW | Dupont | <= 30 cm; the jumper pulled in bring-up 4c | bench |
| UNO | D7 | DHT | SIG | SIGNAL | blue |  | Grove 4-pin (VCC, GND, SIG, NC) | Grove 20-50 cm; direct pin: us-level one-wire timing cannot cross a mux or the expander. Free if the kit has the DHT20 (I2C) | bench |
| UNO | D9 | SERVO | orange (signal) | SIGNAL | blue |  | JR 3-pin brown / red / orange | servo lead ~25 cm; direct pin: a servo needs its 50 Hz train unbroken (PCA9685 to expand) | bench |
| UNO | A0 | MUX1 | SIG | SIGNAL | blue |  | header / Dupont | <= 20 cm; analog, 14-bit | bench |
| UNO | A4 | PCF8575 | SDA | I2C | green | ONE set of pull-ups for the whole bus: 4.7 k to 5V_BOARD (VERIFY each module; remove the rest) | header / Dupont | <= 20 cm | bench |
| UNO | A5 | PCF8575 | SCL | I2C | green | ONE set of pull-ups for the whole bus: 4.7 k to 5V_BOARD (VERIFY each module; remove the rest) | header / Dupont | <= 20 cm | bench |
| UNO | A4/A5 | OLED | SDA / SCL | I2C | green | ONE set of pull-ups for the whole bus: 4.7 k to 5V_BOARD (VERIFY each module; remove the rest) | Grove 4-pin (VCC, GND, SIG, NC) | Grove 20-50 cm; the same two wires as the expander: A4/A5 are a bus, not a pin each | bench |
| UNO | A4/A5 | LCD | SDA / SCL | I2C | green | ONE set of pull-ups for the whole bus: 4.7 k to 5V_BOARD (VERIFY each module; remove the rest) | header / Dupont | <= 30 cm; shares the bus with the expander and the OLED | bench |
| UNO | 5V | RAIL5V | + | 5V_BOARD | orange |  | header / Dupont | <= 20 cm; OUTPUT only, never fed. The board's buck gives 1.2 A total from VIN: see POWER_BUDGET | bench |
| UNO | GND | STAR | GND | GND | black |  | screw terminal | <= 30 cm; the pump's 12 V return never passes here | bench |
| BRICK | 12V+ | UNO | VIN (barrel) | 12V | red | 1 A fuse F2, + leg only | barrel 5.5/2.1 mm, centre + | the servo and the relay coil come out of this: do NOT run them on USB power (500 mA port) | bench |
| RAIL5V | + | MUX1 | VCC | 5V_BOARD | orange | 100 nF at the module |  |  | bench |
| RAIL5V | + | PCF8575 | VCC | 5V_BOARD | orange | 100 nF at the module |  |  | bench |
| RAIL5V | + | HALL_SCREW | + (middle) | 5V_BOARD | orange |  | 3-pin S / + (middle) / - |  | bench |
| RAIL5V | + | HALL_HOME | + (middle) | 5V_BOARD | orange |  | 3-pin S / + (middle) / - |  | bench |
| RAIL5V | + | HALL_FLOAT | + (middle) | 5V_BOARD | orange |  | 3-pin S / + (middle) / - |  | bench |
| RAIL5V | + | FLOW | red | 5V_BOARD | orange |  |  | 5V_BOARD ONLY, never 12 V: the pulses swing to the supply | bench |
| RAIL5V | + | DHT | VCC | 5V_BOARD | orange |  | Grove 4-pin (VCC, GND, SIG, NC) |  | bench |
| RAIL5V | + | LDR | VCC | 5V_BOARD | orange |  | Grove 4-pin (VCC, GND, SIG, NC) |  | bench |
| RAIL5V | + | OLED | VCC | 5V_BOARD | orange |  | Grove 4-pin (VCC, GND, SIG, NC) |  | bench |
| RAIL5V | + | LCD | VCC | 5V_BOARD | orange |  | Dupont | the backlight is most of the ~60 mA the two screens draw | bench |
| RAIL5V | + | MOIST1 | VCC | 5V_BOARD | orange |  | JST-PH 2.0 3-pin (VCC, GND, AOUT) | lead + extension <= 1.5 m | bench |
| RAIL5V | + | MOIST2 | VCC | 5V_BOARD | orange |  | JST-PH 2.0 3-pin (VCC, GND, AOUT) | lead + extension <= 1.5 m | bench |
| RAIL5V | + | MOIST3 | VCC | 5V_BOARD | orange |  | JST-PH 2.0 3-pin (VCC, GND, AOUT) | lead + extension <= 1.5 m | bench |
| RAIL5V | + | MOIST4 | VCC | 5V_BOARD | orange |  | JST-PH 2.0 3-pin (VCC, GND, AOUT) | lead + extension <= 1.5 m | bench |
| RAIL5V | + | MOIST5 | VCC | 5V_BOARD | orange |  | JST-PH 2.0 3-pin (VCC, GND, AOUT) | lead + extension <= 1.5 m | bench |
| RAIL5V | + | RELAY | VCC | 5V_BOARD | orange |  | Dupont | coil ~80 mA (VERIFY); if the module has a JD-VCC jumper, leaving it fitted is what puts the coil on this rail | bench |
| RAIL5V | + | SERVO | red | 5V_BOARD | orange |  | JR 3-pin | its OWN pair from the rail's feed point, plus 470-1000 uF and 100 nF AT THE SERVO PLUG: that cap, not the rail, is what stops a stall dip resetting the board | bench |
| STAR | GND | RAILGND | - | GND | black |  |  | one wire, star -> breadboard GND rail | bench |
| RAILGND | - | MUX1 | GND | GND | black |  |  |  | bench |
| RAILGND | - | PCF8575 | GND | GND | black |  |  |  | bench |
| RAILGND | - | HALL_SCREW | - | GND | black |  | 3-pin S / + (middle) / - |  | bench |
| RAILGND | - | HALL_HOME | - | GND | black |  | 3-pin S / + (middle) / - |  | bench |
| RAILGND | - | HALL_FLOAT | - | GND | black |  | 3-pin S / + (middle) / - |  | bench |
| RAILGND | - | FLOW | black | GND | black |  |  |  | bench |
| RAILGND | - | DHT | GND | GND | black |  | Grove 4-pin (VCC, GND, SIG, NC) |  | bench |
| RAILGND | - | LDR | GND | GND | black |  | Grove 4-pin (VCC, GND, SIG, NC) |  | bench |
| RAILGND | - | OLED | GND | GND | black |  | Grove 4-pin (VCC, GND, SIG, NC) |  | bench |
| RAILGND | - | LCD | GND | GND | black |  | Dupont |  | bench |
| RAILGND | - | MOIST1 | GND | GND | black |  | JST-PH 2.0 3-pin (VCC, GND, AOUT) |  | bench |
| RAILGND | - | MOIST2 | GND | GND | black |  | JST-PH 2.0 3-pin (VCC, GND, AOUT) |  | bench |
| RAILGND | - | MOIST3 | GND | GND | black |  | JST-PH 2.0 3-pin (VCC, GND, AOUT) |  | bench |
| RAILGND | - | MOIST4 | GND | GND | black |  | JST-PH 2.0 3-pin (VCC, GND, AOUT) |  | bench |
| RAILGND | - | MOIST5 | GND | GND | black |  | JST-PH 2.0 3-pin (VCC, GND, AOUT) |  | bench |
| RAILGND | - | RELAY | GND | GND | black |  | Dupont | coil return | bench |
| SERVO | brown | STAR | GND | GND | black |  | JR 3-pin | to the star, not the sensor rail: keeps the stall dip out of the ADC ground | bench |
| MUX1 | EN | RAILGND | - | GND | black |  |  | EN tied LOW: mux always enabled (breakouts may pull EN down with 10 k) | bench |
| MOIST1 | AOUT | MUX1 | C0 | SIGNAL | blue |  | JST-PH 2.0 3-pin (VCC, GND, AOUT) | ~10 k source; 0-3 V | bench |
| MOIST2 | AOUT | MUX1 | C1 | SIGNAL | blue |  | JST-PH 2.0 3-pin (VCC, GND, AOUT) | ~10 k source; 0-3 V | bench |
| MOIST3 | AOUT | MUX1 | C2 | SIGNAL | blue |  | JST-PH 2.0 3-pin (VCC, GND, AOUT) | ~10 k source; 0-3 V | bench |
| MOIST4 | AOUT | MUX1 | C3 | SIGNAL | blue |  | JST-PH 2.0 3-pin (VCC, GND, AOUT) | ~10 k source; 0-3 V | bench |
| MOIST5 | AOUT | MUX1 | C4 | SIGNAL | blue |  | JST-PH 2.0 3-pin (VCC, GND, AOUT) | ~10 k source; 0-3 V | bench |
| LDR | SIG | MUX1 | C5 | SIGNAL | blue |  | Grove 4-pin (VCC, GND, SIG, NC) | 0-5 V | bench |
| PCF8575 | P0 | MUX1 | S0 | SIGNAL | blue |  |  | <= 20 cm | bench |
| PCF8575 | P1 | MUX1 | S1 | SIGNAL | blue |  |  | <= 20 cm | bench |
| PCF8575 | P2 | MUX1 | S2 | SIGNAL | blue |  |  | <= 20 cm | bench |
| PCF8575 | P3 | MUX1 | S3 | SIGNAL | blue |  |  | <= 20 cm | bench |
| HALL_HOME | S | PCF8575 | P4 | SIGNAL | blue | 10 k pull-up to 5V_BOARD at the breadboard (R3) | 3-pin S / + (middle) / - | <= 50 cm; a level, not a pulse train: the expander is fast enough (a 2-byte read is ~0.3 ms). Write P4 HIGH before reading it (quasi-bidirectional) | bench |
| BRICK | 12V+ | PERFBOARD | 12V_IN | 12V | red | T 3 A slow-blow F1, + leg only | screw terminal | >= 0.5 mm2 | bench |
| PERFBOARD | 12V_OUT | RELAY | COM | 12V | red |  | screw terminal | >= 0.5 mm2; the relay switches the + leg | bench |
| RELAY | NO | PUMP | + | PUMP_SW | purple |  | screw terminal | >= 0.5 mm2; NO, not NC: no coil = no pump | bench |
| BRICK | 12V- | STAR | GND | GND | black |  | screw terminal | >= 0.5 mm2 | bench |
| PUMP | - | STAR | GND | GND | black |  | screw terminal | >= 0.5 mm2; straight to the star, never the board's GND pin | bench |
| PCF8575 | P0 | MUX2 | S0 | SIGNAL | blue |  |  | select lines shared with MUX1 | later |
| PCF8575 | P1 | MUX2 | S1 | SIGNAL | blue |  |  | select lines shared with MUX1 | later |
| PCF8575 | P2 | MUX2 | S2 | SIGNAL | blue |  |  | select lines shared with MUX1 | later |
| PCF8575 | P3 | MUX2 | S3 | SIGNAL | blue |  |  | select lines shared with MUX1 | later |
| PCF8575 | P6 | MUX2 | EN | SIGNAL | blue |  |  |  | later |
| MUX2 | SIG | UNO | A1 | SIGNAL | blue |  |  |  | later |

</details>

## Mux, expander, I2C

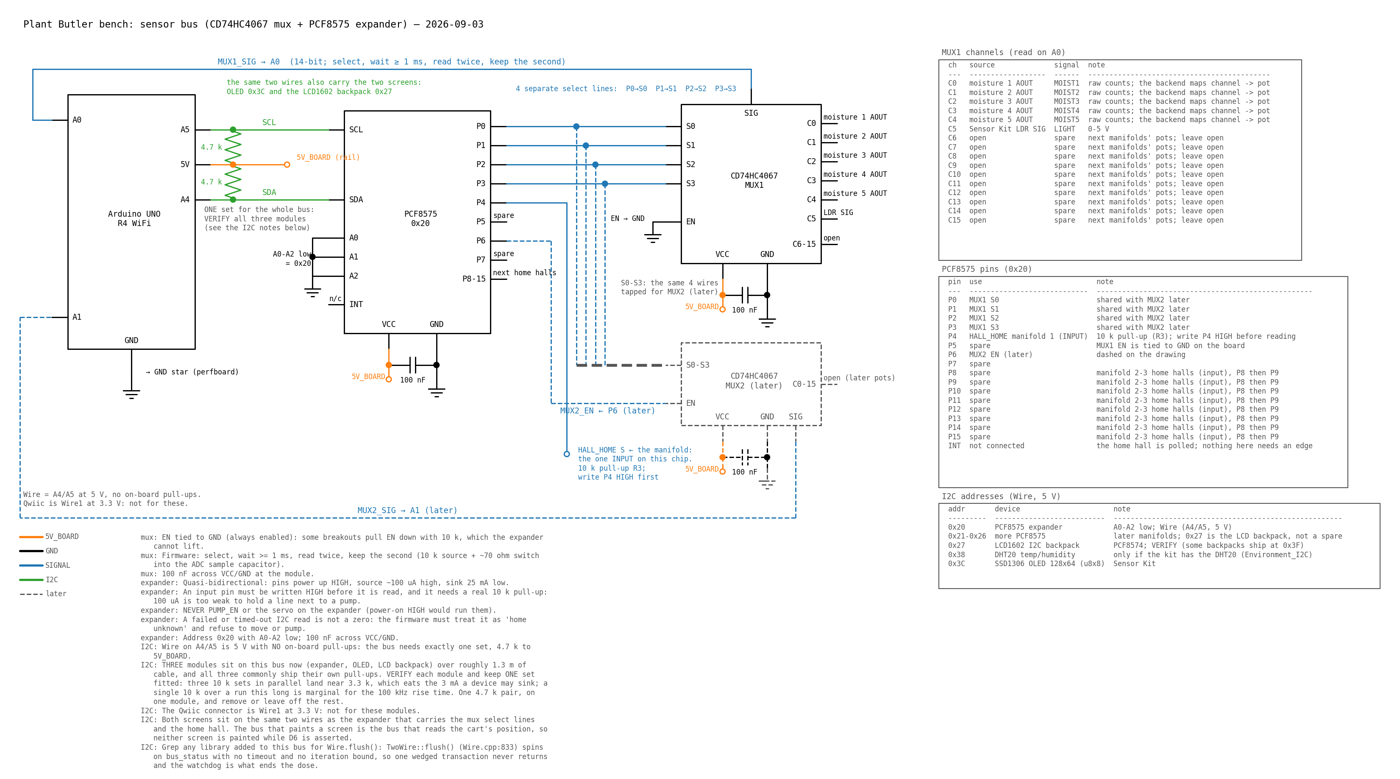
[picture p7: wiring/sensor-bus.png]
sensor-bus


*sensor-bus.png* — P0-P3 -> S0-S3, EN to GND, C0-C4 moisture and C5 light, SIG -> A0; the I2C pull-ups sit on the expander module; 100 nF at each chip; MUX2 and its select lines dashed (later). The two screens share this SDA/SCL pair: they are in the address table, not drawn as blocks.

### CD74HC4067 MUX1 channels (SIG -> A0, 14-bit)

| channel | source | signal | note |
| --- | --- | --- | --- |
| C0 | moisture 1 AOUT | MOIST1 | raw counts; the backend maps channel -> pot |
| C1 | moisture 2 AOUT | MOIST2 | raw counts; the backend maps channel -> pot |
| C2 | moisture 3 AOUT | MOIST3 | raw counts; the backend maps channel -> pot |
| C3 | moisture 4 AOUT | MOIST4 | raw counts; the backend maps channel -> pot |
| C4 | moisture 5 AOUT | MOIST5 | raw counts; the backend maps channel -> pot |
| C5 | Sensor Kit LDR SIG | LIGHT | 0-5 V |
| C6 | open | spare | next manifolds' pots; leave open |
| C7 | open | spare | next manifolds' pots; leave open |
| C8 | open | spare | next manifolds' pots; leave open |
| C9 | open | spare | next manifolds' pots; leave open |
| C10 | open | spare | next manifolds' pots; leave open |
| C11 | open | spare | next manifolds' pots; leave open |
| C12 | open | spare | next manifolds' pots; leave open |
| C13 | open | spare | next manifolds' pots; leave open |
| C14 | open | spare | next manifolds' pots; leave open |
| C15 | open | spare | next manifolds' pots; leave open |

- EN tied to GND (always enabled): some breakouts pull EN down with 10 k, which the expander cannot lift.
- Firmware: select, wait >= 1 ms, read twice, keep the second (10 k source + ~70 ohm switch into the ADC sample capacitor).
- 100 nF across VCC/GND at the module.

### PCF8575 pins (0x20)

| pin | use | note |
| --- | --- | --- |
| P0 | MUX1 S0 | shared with MUX2 later |
| P1 | MUX1 S1 | shared with MUX2 later |
| P2 | MUX1 S2 | shared with MUX2 later |
| P3 | MUX1 S3 | shared with MUX2 later |
| P4 | HALL_HOME manifold 1 (INPUT) | 10 k pull-up (R3); write P4 HIGH before reading |
| P5 | spare | MUX1 EN is tied to GND on the board |
| P6 | MUX2 EN (later) | dashed on the drawing |
| P7 | spare |  |
| P8 | spare | manifold 2-3 home halls (input), P8 then P9 |
| P9 | spare | manifold 2-3 home halls (input), P8 then P9 |
| P10 | spare | manifold 2-3 home halls (input), P8 then P9 |
| P11 | spare | manifold 2-3 home halls (input), P8 then P9 |
| P12 | spare | manifold 2-3 home halls (input), P8 then P9 |
| P13 | spare | manifold 2-3 home halls (input), P8 then P9 |
| P14 | spare | manifold 2-3 home halls (input), P8 then P9 |
| P15 | spare | manifold 2-3 home halls (input), P8 then P9 |
| INT | not connected | the home hall is polled; nothing here needs an edge |

- Quasi-bidirectional: pins power up HIGH, source ~100 uA high, sink 25 mA low.
- An input pin must be written HIGH before it is read, and it needs a real 10 k pull-up: 100 uA is too weak to hold a line next to a pump.
- NEVER PUMP_EN or the servo on the expander (power-on HIGH would run them).
- A failed or timed-out I2C read is not a zero: the firmware must treat it as 'home unknown' and refuse to move or pump.
- Address 0x20 with A0-A2 low; 100 nF across VCC/GND.

### I2C addresses

| address | device | note |
| --- | --- | --- |
| 0x20 | PCF8575 expander | A0-A2 low; Wire (A4/A5, 5 V) |
| 0x21-0x26 | more PCF8575 | later manifolds; 0x27 is the LCD backpack, not a spare |
| 0x27 | LCD1602 I2C backpack | PCF8574; VERIFY (some backpacks ship at 0x3F) |
| 0x38 | DHT20 temp/humidity | only if the kit has the DHT20 (Environment_I2C) |
| 0x3C | SSD1306 OLED 128x64 (u8x8) | Sensor Kit |

- Wire on A4/A5 is 5 V with NO on-board pull-ups: the bus needs exactly one set, 4.7 k to 5V_BOARD.
- THREE modules sit on this bus now (expander, OLED, LCD backpack) over roughly 1.3 m of cable, and all three commonly ship their own pull-ups. VERIFY each module and keep ONE set fitted: three 10 k sets in parallel land near 3.3 k, which eats the 3 mA a device may sink; a single 10 k over a run this long is marginal for the 100 kHz rise time. One 4.7 k pair, on one module, and remove or leave off the rest.
- The Qwiic connector is Wire1 at 3.3 V: not for these modules.
- Both screens sit on the same two wires as the expander that carries the mux select lines and the home hall. The bus that paints a screen is the bus that reads the cart's position, so neither screen is painted while D6 is asserted.
- Grep any library added to this bus for Wire.flush(): TwoWire::flush() (Wire.cpp:833) spins on bus_status with no timeout and no iteration bound, so one wedged transaction never returns and the watchdog is what ends the dose.

## Pump driver and interlock

A bought relay module switches the 12 V + leg: COM comes from the brick through F1, NO goes to the pump, and the pump's return goes straight to the star. D6 drives the module's IN through nothing but a wire and R1, which holds the OFF level whenever D6 is not an asserted output. The float hall reaches D5 directly, with R2 lifting an open line to the "not OK" level.

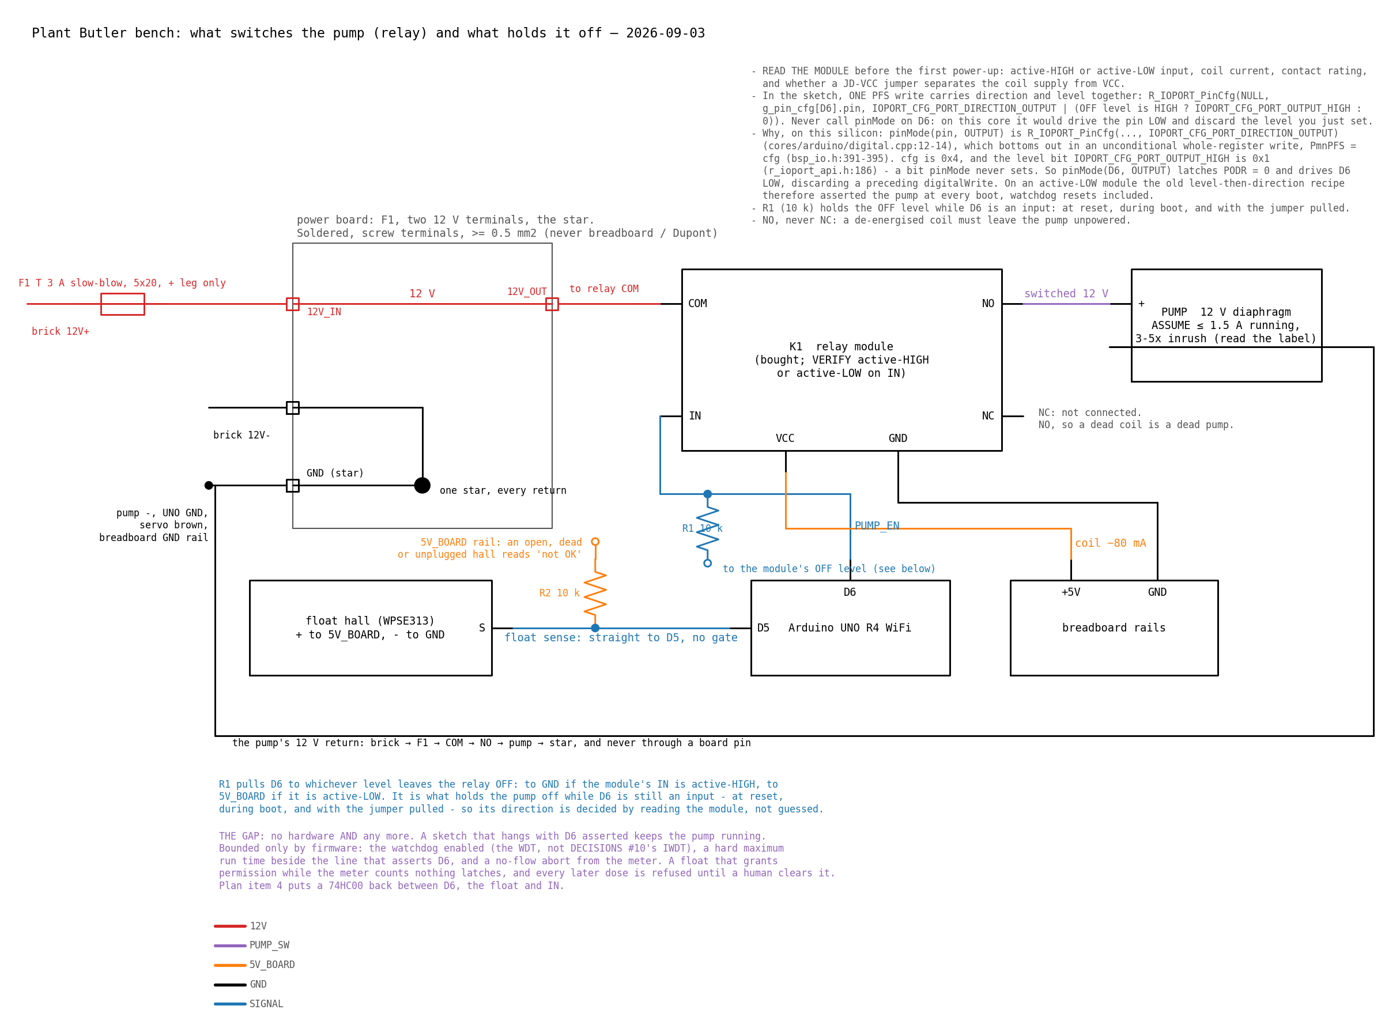
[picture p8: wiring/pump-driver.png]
pump-driver


*pump-driver.png* — follow the 12 V loop brick -> F1 -> COM -> NO -> pump + -> pump - -> star, and note that it crosses no board pin; D6 reaches only the relay's IN, with R1 holding the OFF level; the float hall goes straight to D5 with R2, through no gate.

### Power board terminals

| terminal | wire | net | gauge |
| --- | --- | --- | --- |
| 12V_IN | brick 12V+ via F1 (T 3 A slow-blow) | 12V | >= 0.5 mm2 |
| 12V_OUT | relay COM | 12V | >= 0.5 mm2 |
| GND (star) | brick 12V-, pump -, servo brown, UNO GND, breadboard GND rail | GND | >= 0.5 mm2 for the 12 V returns |

### Relay module terminals

| terminal | wire | net | gauge |
| --- | --- | --- | --- |
| VCC | 5V_BOARD rail | 5V_BOARD | Dupont |
| GND | breadboard GND rail | GND | Dupont |
| IN | UNO D6, with R1 10 k to the module's OFF level | SIGNAL | Dupont |
| COM | power board 12V_OUT (brick + leg, after F1) | 12V | >= 0.5 mm2 |
| NO | pump + | PUMP_SW | >= 0.5 mm2 |
| NC | not connected | SIGNAL | - |

- READ THE MODULE before the first power-up: active-HIGH or active-LOW input, coil current, contact rating, and whether a JD-VCC jumper separates the coil supply from VCC.
- In the sketch, ONE PFS write carries direction and level together: R_IOPORT_PinCfg(NULL, g_pin_cfg[D6].pin, IOPORT_CFG_PORT_DIRECTION_OUTPUT | (OFF level is HIGH ? IOPORT_CFG_PORT_OUTPUT_HIGH : 0)). Never call pinMode on D6: on this core it would drive the pin LOW and discard the level you just set.
- Why, on this silicon: pinMode(pin, OUTPUT) is R_IOPORT_PinCfg(..., IOPORT_CFG_PORT_DIRECTION_OUTPUT) (cores/arduino/digital.cpp:12-14), which bottoms out in an unconditional whole-register write, PmnPFS = cfg (bsp_io.h:391-395). cfg is 0x4, and the level bit IOPORT_CFG_PORT_OUTPUT_HIGH is 0x1 (r_ioport_api.h:186) - a bit pinMode never sets. So pinMode(D6, OUTPUT) latches PODR = 0 and drives D6 LOW, discarding a preceding digitalWrite. On an active-LOW module the old level-then-direction recipe therefore asserted the pump at every boot, watchdog resets included.
- R1 (10 k) holds the OFF level while D6 is an input: at reset, during boot, and with the jumper pulled.
- NO, never NC: a de-energised coil must leave the pump unpowered.
- Never PWM the contacts. ~10^5 mechanical cycles is decades at a few doses a day; a switched-on-and-off duty cycle is not.
- Optional, for contact life: a 100 ohm + 100 nF snubber across COM/NO. Not needed on the bench.

### Parts

| ref | value | role |
| --- | --- | --- |
| F1 | T 3 A slow-blow, 5x20 | pump branch, + leg only; value fixed after bring-up 7d |
| F2 | 1 A, 5x20 | UNO VIN, + leg only |
| K1 | 1-channel relay module, 5 V coil | switches the 12 V + leg: COM from F1, NO to pump + |
| R1 | 10 k | D6 to the module's OFF level: pull-down if active-HIGH, pull-up if active-LOW |
| R2 | 10 k | float hall S pull-up to 5V_BOARD: unplugged or dead = the 'not OK' level |
| R3 | 10 k | home hall S pull-up to 5V_BOARD (expander P4) |
| R4 | 10 k | flow-meter pulse pull-up to 5V_BOARD (D2), behind the 1 k series: an unplugged meter must read a firm level, not oscillate - a floating counted-pulse input is indistinguishable from flow |
| C1 | 470-1000 uF electrolytic | across the servo's 5 V / GND AT THE PLUG |
| C2 | 100 nF | beside C1, and one across each of the mux and the expander |

### What stops the pump, and what holds it there

Read the last column. Rows marked *hardware* hold whatever the sketch does; rows marked *FIRMWARE* are only as good as the code, which is the price of building this from parts in hand.

| case | D6 | float | pump | held by |
| --- | --- | --- | --- | --- |
| watering | asserted | above the line: magnet at the hall | RUNS | firmware |
| firmware idle | at rest | any | off | hardware: no coil, no contact |
| level past the margin | firmware drops it | below the line: the magnet has left the hall | off | FIRMWARE |
| float hall unplugged, GND lead off, or dead | firmware drops it | reads 'not OK' (R2) | off | FIRMWARE, on a hardware sense path |
| float says OK, the meter sees nothing | firmware drops it | reads OK, and is not believed | off, and every later dose refused | FIRMWARE: the contradiction latch, until `clear contra` |
| MCU in reset / boot / D6 not yet OUTPUT / jumper pulled | input -> OFF level (R1) | any | off | hardware |
| board 5 V absent (USB out, board dead) | - | any | off | hardware: coil unpowered |
| 12 V absent | any | any | off | hardware: pump unpowered |
| I2C hung, home hall unreadable | firmware drops it | any | off | FIRMWARE: unknown position must refuse |
| firmware hung with D6 already asserted | stuck asserted | any | RUNS until the watchdog resets the board | WATCHDOG: the WDT, register-started (firmware spec 2.5). See the gap below |
| firmware hung and the watchdog off | stuck asserted | any | RUNS until someone pulls the plug | nothing |

- The relay's own failure direction is dry: every open, unplug, power loss and reset de-energises the coil and the contacts fall open. That part is better than the MOSFET it replaces, which needed a gate pull-down to manage it.
- THE GAP: there is no longer a hardware AND between 'firmware says pump' and 'the tank has water'. A sketch that hangs with D6 already asserted keeps the pump running. Three things bound it, and all three are firmware: the RA4M1 watchdog enabled (a hang resets the board, D6 reverts to an input, R1 opens the relay), a hard maximum run time in the same code path that asserts D6, and a no-flow abort from the flow meter. Write all three or none of this holds.
- The watchdog that is written is the WDT, register-started and PCLKB-clocked, not the IWDT that DECISIONS #10 names: the IWDT auto-starts from OFS0 option bytes the Arduino core does not expose, and a wrong one locks the board out of uploads. Firmware spec 2.5 has the granted window; status prints it.
- A fifth case the hardware cannot see: the float grants permission and the meter counts nothing. The two sensors contradict each other, the safe reading is a stuck float over an empty tank, and the firmware latches - every later dose refused until someone types `clear contra`.
- The float is mounted so that ALLOW is the active state (magnet present). Every sensor failure - an open line, a dead hall, an unplugged connector, a lost 5 V - therefore reads as refuse, never as permission.
- A float that still says full after more water than the tank holds has been pumped since the last refill is presumed stuck: refuse and page. A float still saying empty minutes after a refill is presumed dead: page (the rules are dry on empty already). The tank's size is what the meter counted between a refill and the float going empty, the median of the last five runs, armed after two.
- Plan item 4 ('Don't flood the flat') puts a hardware interlock back when the parts are in hand: a 74HC00 (or a 74HC08 plus an inverter) between D6, the float and the relay's IN.

### Where the float sits, and why it decides the failure direction

The mechanics choose the sense, and the sense chooses whether a dead sensor reads as permission. The wiring is identical either way; what differs is whether the float's travel is capped by a stop at the trip level.

```
    LEVEL ABOVE THE LINE                     LEVEL BELOW THE LINE
    +-----------------------+                +-----------------------+
    | ~~~~~~~~~~~~~~~~~~~~~ | <- surface     |                       |
    | ~~~~~~~~~~~ ==+== ~~~ | <- STOP        |            ==+==      | <- STOP
    | ~~~~~~~~~~~ +-|-+ ~~~ |                |              |        |    (float no
    | ~~~~~~~~~~~ | F |#=====> hall          |              |   #====> hall
    | ~~~~~~~~~~~ +-|-+ ~~~ |    magnet AT   | ~~~~~~~~~~~~ | ~~~~~~ |     longer
    | ~~~~~~~~~~~   |   ~~~ |    the hall    | ~~~~~~~ +----|----+ ~~ |     near it)
    |               |       |                | ~~~~~~~ |    F    | ~~ |
    +---------------+-------+                +---------+---------+---+

      magnet present = water OK = allow        magnet away = refuse
```

| arrangement | magnet at the hall | allowed is | sensor failure reads as | verdict |
| --- | --- | --- | --- | --- |
| CHOSEN: float travel capped by a STOP at the trip level, hall at the stop (sliding on a stem, or a hinged arm as in a cistern) | whenever the level is above the line | the ACTIVE state | refuse (fail-safe) | built this way |
| rejected: free float, hall low in the tank | only once the level has dropped to it | the PASSIVE state | ALLOW (fail-dangerous) | easier, but every dead sensor grants permission |

- The stop is the whole mechanism: without it the float rides the surface up and away, and a fixed sensor can only be placed where it sees 'empty'.
- Sense in the sketch: magnet present (hall output LOW on a WPSE313) = water above the line = the only state in which a dose may start. Everything else - no magnet, an open line, a dead or unplugged hall, a lost 5 V - is 'not OK', because R2 lifts the line and the firmware reads that as refuse.
- Set the stop so the trip level leaves enough water above the pump inlet for one full dose plus the priming volume; the margin, not the sensor, is what keeps the pump wet.
- Wiring: one hall on D5 with a 10 k pull-up (R2). Bring-up 5a and 5b prove both directions.

## Parts list

ASSUME = ordered, exact model unknown until it arrives; VERIFY / READ THE LABEL = check before wiring; the drawings show these as labelled blocks.

| part | qty | status | verify |
| --- | --- | --- | --- |
| Arduino UNO R4 WiFi | 1 | in hand |  |
| PCF8575 I2C expander module | 1 | in hand | VERIFY whether the module carries SDA/SCL pull-ups: three sets on this bus is two too many. A0-A2 low -> 0x20 |
| CD74HC4067 mux module | 1 (+1 later) | in hand | VERIFY EN pull-down on the breakout (EN goes to GND regardless) |
| Whadda WPSE313 hall module | 3 of 8 | in hand | VERIFY on-board pull-up (ours is fitted regardless); LED lights at the magnet's south pole |
| SG90 continuous-rotation servo | 1 | in hand | on 5V_BOARD with C1 at the plug; board fed from VIN, not USB |
| Sensor Kit temperature/humidity | 1 | in hand | READ THE MODULE: DHT11 (D7, Environment.setPin(7)) or DHT20 (I2C 0x38, Environment_I2C) |
| Sensor Kit light (LDR) | 1 | in hand |  |
| Sensor Kit OLED (SSD1306 128x64, u8x8) | 1 | in hand | 0x3C on Wire, 5 V; shares A4/A5 with the expander. VERIFY whether the module carries SDA/SCL pull-ups |
| LCD1602 with an I2C backpack | 1 | in hand | VERIFY the backpack's address: PCF8574 boards ship at 0x27 or 0x3F (A0-A2 solder jumpers) - note which yours is, bring-up 1 accepts either. VERIFY whether it carries SDA/SCL pull-ups. The backlight is most of the two screens' ~60 mA |
| capacitive soil-moisture sensor v1.2/v2.0 | 5 | in hand | AOUT 0-3 V, ~10 k source |
| neodymium magnets (cart, screw, float) | 3+ | in hand | VERIFY polarity: south pole toward the hall face |
| relay module, 1 channel, 5 V coil (TRU COMPONENTS TC-9927156 or like) | 1 | in hand | READ THE MODULE: active-HIGH or active-LOW IN; coil current; contact rating (>= 2 A at 12 V DC); JD-VCC jumper fitted = coil on 5V_BOARD. Sets R1's direction and the sketch's OFF level |
| pump, 12 V DC diaphragm | 1 | ASSUME | READ THE LABEL: voltage, running current (assume <= 1.5 A), inrush 3-5x; measure in 7d, then fix F1 |
| 12 V brick | 1 | ASSUME >= 3 A | READ THE LABEL: amps (a 2 A brick browns out at pump start) |
| flow meter YF-S401 | 1 | ASSUME | READ THE SUFFIX: -0207 (0.2-3 L/min) or -3507 (0.3-6 L/min); ~5880 pulses/L; vertical, flow up; 5V_BOARD only |
| 74HC00 quad NAND, DIP-14 + 5 V UBEC | 1 each | later, not now | the hardware interlock (plan item 4) and the servo supply once several servos move at once |
| fuse holders 5x20 + T 3 A slow-blow + 1 A | 2 + spares | to buy | F1 value fixed after 7d |
| flyback / snubber parts | - | not needed | the relay module carries its own coil diode. No 1N5819 across the pump: contacts take the kick as an arc, not an avalanche. If a MOSFET ever comes back, use a 3 A part (1N5822 / SB360), not a 1 A 1N5819 on a 1.5 A pump |
| resistors 1 k x1, 4.7 k x2, 10 k x5 | set | to buy | 10 k: R1, R2, R3, R4 and a spare; 1 k: flow-meter series; 4.7 k for the bus's one set of I2C pull-ups |
| 470-1000 uF electrolytic (C1, >= 10 V) + 100 nF ceramic x4 | 1 + 4 | to buy | C1 at the SERVO PLUG, not at the board; 100 nF for mux, expander, servo, spare |
| perfboard, screw terminals (>= 6 positions), wire >= 0.5 mm2 red/black/purple | 1 set | to buy | F1, the two 12 V terminals and the star; soldered; never breadboard in the 12 V loop |
| breadboard, Dupont jumpers (colours per the table), JST-PH 2.0 leads x5, Grove cables x2 | 1 set | to buy |  |
| silicone tube 30-50 cm + tube for the meter's 7 mm outlet and the manifold inlet | 1 set | to buy | meter variant sets the intake bore |
| reservoir with a keyed float carrying a magnet; bucket | 1 | to build | the float's UP travel must be capped by a stop at the trip level, with the hall at that stop: magnet present = water above the line = the only state that allows a dose |

### Read the label first

These decide a wire, a fuse or a library call, so they come before anything is plugged in:

- **Whadda WPSE313 hall module** — VERIFY on-board pull-up (ours is fitted regardless); LED lights at the magnet's south pole
- **Sensor Kit temperature/humidity** — READ THE MODULE: DHT11 (D7, Environment.setPin(7)) or DHT20 (I2C 0x38, Environment_I2C)
- **relay module, 1 channel, 5 V coil (TRU COMPONENTS TC-9927156 or like)** — READ THE MODULE: active-HIGH or active-LOW IN; coil current; contact rating (>= 2 A at 12 V DC); JD-VCC jumper fitted = coil on 5V_BOARD. Sets R1's direction and the sketch's OFF level
- **pump, 12 V DC diaphragm** — READ THE LABEL: voltage, running current (assume <= 1.5 A), inrush 3-5x; measure in 7d, then fix F1
- **12 V brick** — READ THE LABEL: amps (a 2 A brick browns out at pump start)
- **flow meter YF-S401** — READ THE SUFFIX: -0207 (0.2-3 L/min) or -3507 (0.3-6 L/min); ~5880 pulses/L; vertical, flow up; 5V_BOARD only

## Hydraulic chain

The reservoir sits ABOVE the pump inlet so any pump type is gravity-primed; the flow meter is vertical with the flow upward. Tubing is the teal strip on the overview drawing.

| stage | detail |
| --- | --- |
| reservoir | ABOVE the pump inlet (gravity-primed); float travel capped by a stop at the trip level, hall at the stop |
| pump | 12 V diaphragm, inlet below the reservoir surface |
| silicone tube 30-50 cm | soft: pulsation damper |
| flow meter | vertical, flow UPWARD, tilt <= 5 deg; no pulses below its flow floor |
| manifold inlet | one manifold, 5 outlets |
| outlets 1-5 | pots, or the bucket on the bench |

## Power

One 5 V rail: **5V_BOARD** (orange), the UNO's own 5 V pin, an output and never fed from outside. It carries the sensors, the relay coil and the servo, because the R4's ISL854102 buck gives 1.2 A total from VIN where the R3's linear regulator could not - so the board must be fed from the barrel jack, not a USB port, once the servo moves. The servo takes its own pair from the rail's feed point with C1 (470-1000 uF) at its plug, and returns to the star rather than to the sensor ground. One GND star on the power board; the pump's 12 V return reaches it without passing a board pin. Fuses sit in the + leg only, never in a return.

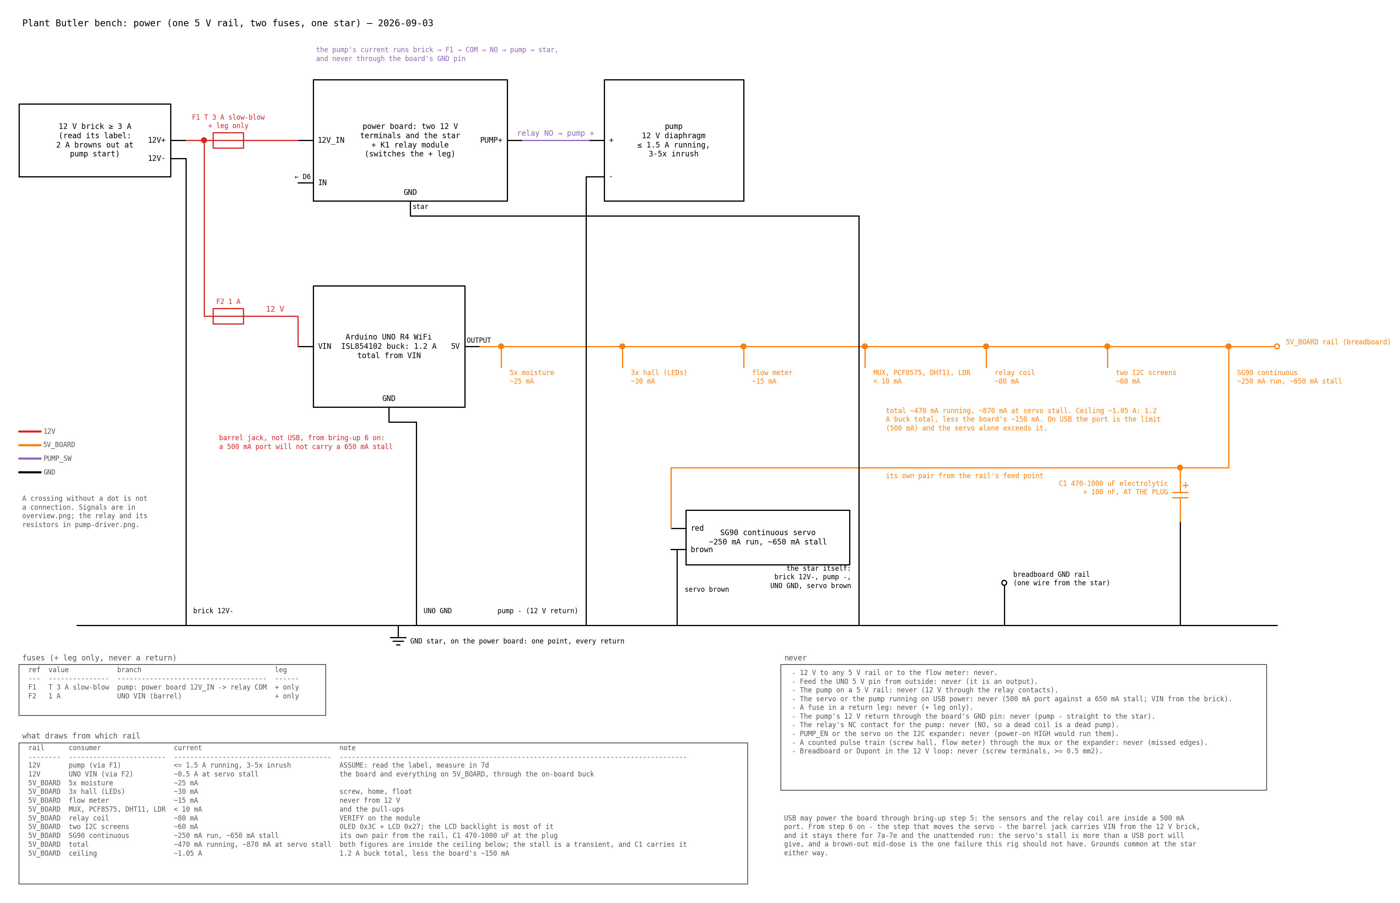
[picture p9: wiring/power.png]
power


*power.png* — one 5 V rail out of the board's buck, with the servo on its own pair and C1 at its plug; F1 and F2 in the + legs only; the pump's return reaching the star without passing a board pin; a current next to every consumer and the 1.05 A ceiling stated.

### Budget

| rail | consumer | current | note |
| --- | --- | --- | --- |
| 12V | pump (via F1) | <= 1.5 A running, 3-5x inrush | ASSUME: read the label, measure in 7d |
| 12V | UNO VIN (via F2) | ~0.5 A at servo stall | the board and everything on 5V_BOARD, through the on-board buck |
| 5V_BOARD | 5x moisture | ~25 mA |  |
| 5V_BOARD | 3x hall (LEDs) | ~30 mA | screw, home, float |
| 5V_BOARD | flow meter | ~15 mA | never from 12 V |
| 5V_BOARD | MUX, PCF8575, DHT11, LDR | < 10 mA | and the pull-ups |
| 5V_BOARD | relay coil | ~80 mA | VERIFY on the module |
| 5V_BOARD | two I2C screens | ~60 mA | OLED 0x3C + LCD 0x27; the LCD backlight is most of it |
| 5V_BOARD | SG90 continuous | ~250 mA run, ~650 mA stall | its own pair from the rail, C1 470-1000 uF at the plug |
| 5V_BOARD | total | ~470 mA running, ~870 mA at servo stall | both figures are inside the ceiling below; the stall is a transient, and C1 carries it |
| 5V_BOARD | ceiling | ~1.05 A | 1.2 A buck total, less the board's ~150 mA |

### Fuses

| ref | value | branch | leg |
| --- | --- | --- | --- |
| F1 | T 3 A slow-blow | pump: power board 12V_IN -> relay COM | + only |
| F2 | 1 A | UNO VIN (barrel) | + only |

USB may power the board through bring-up step 5: the sensors and the relay coil are inside a 500 mA port. From step 6 on - the step that moves the servo - the barrel jack carries VIN from the 12 V brick, and it stays there for 7a-7e and the unattended run: the servo's stall is more than a USB port will give, and a brown-out mid-dose is the one failure this rig should not have. Grounds common at the star either way.

### Never

- 12 V to any 5 V rail or to the flow meter: never.
- Feed the UNO 5 V pin from outside: never (it is an output).
- The pump on a 5 V rail: never (12 V through the relay contacts).
- The servo or the pump running on USB power: never (500 mA port against a 650 mA stall; VIN from the brick).
- A fuse in a return leg: never (+ leg only).
- The pump's 12 V return through the board's GND pin: never (pump - straight to the star).
- The relay's NC contact for the pump: never (NO, so a dead coil is a dead pump).
- PUMP_EN or the servo on the I2C expander: never (power-on HIGH would run them).
- A counted pulse train (screw hall, flow meter) through the mux or the expander: never (missed edges).
- Breadboard or Dupont in the 12 V loop: never (screw terminals, >= 0.5 mm2).

## Bench command set

The bench firmware is a separate deliverable under the plan pitches "Pump on command" and "Bench rig"; it is not in this directory. This wiring assumes it provides these serial commands, which the bring-up below uses. The commands that can move the cart or start the pump live only in the bring-up binary; the one left running unattended has no console path to D6:

| command | binary | does |
| --- | --- | --- |
| `i2c` | bench + bring-up | scan Wire, list addresses (expect 0x20, 0x3C and the LCD backpack at 0x27 or 0x3F; 0x38 if the kit has the DHT20) |
| `mux <0-15>\|all` | bench + bring-up | select, wait >= 1 ms, read twice, print the second (14-bit raw) |
| `hall` | bench + bring-up | stream screw (D3), home (expander P4) and float (D5) states; an I2C read error prints 'home unknown' |
| `flow` | bench + bring-up | pulses per second on D2 and total since reset |
| `clear contra` | bench + bring-up | release the contradiction latch: the only way back after 'float says OK, the meter saw nothing' |
| `status` | bench + bring-up | pins, counts, uptime, last error (`last=`), which binary is running (`build=`), `dry=`, `contra=`, the compiled pump ON/OFF level, and whether the WDT is enabled, the window it was granted and whether its counter is moving |
| `stop` | bench + bring-up | cuts a dose in progress |
| `dry on\|off` | bench + bring-up | latch: while it is on, every dose is refused (`dry on` also cuts a dose in progress). It is the only way back from a latch, and a reset taken mid-dose sets one by itself: bring-up 4a, 4b and 7c all need a `dry off` after them (4c pulls a jumper, not the reset line, and does not latch) |
| `help` | bench + bring-up | one screen: the commands this binary has |
| `servo <1000-2000> <ms>` | bring-up only | bounded: drive the servo at that pulse width (us, absolute, no sign) for <= cap ms, then stop |
| `home` | bring-up only | run toward home until HALL_HOME, bounded time, zero the count |
| `goto <1-5>` | bring-up only | step to the outlet counting screw pulses, bounded |
| `pump <ms> [prime] [hang]` | bring-up only | assert D6 for <= cap ms; refused when the float reads 'not OK'; aborts on no flow within the timeout; the cap lives in the same code path that asserts D6. 'prime' extends the no-flow window and caps the dose at 20 s - it removes no abort. 'hang' starves the watchdog (7c) |
| `calib` | bring-up only | one fixed 10 s primed dose into a measuring jug, for 7b: read the jug, divide the pulse total by the litres, and hand the number to `cal` |
| `noinit pattern` | bring-up only | write a known pattern into the .noinit block, then force a watchdog reset (7c') and read it back in `status`: proves the latches survive the reset the way the code claims |
| `cal <pulses per litre>` | bring-up only | set the meter calibration at runtime, bounded to a sane range; 7b's number |

## Bring-up order

In this order, each step proving one thing. Steps 4a-4c exercise the relay dry, with no 12 V on COM and nothing plumbed, because that is the cheapest moment to discover the module's input polarity. Step 7c proves the watchdog, which on this bench is the only thing between a hung sketch and a running pump. Step 7e swaps the bring-up binary for the unattended one before the 48-hour run, and checks that the pump commands went with it.

**Any reset taken mid-dose latches dry.** The board sets `dose_in_flight` before it asserts D6 and clears it after it drops it, so a RESET or a watchdog reset in between comes back with the dry latch set and `last=resetmid` - and while that latch stands, every dose is refused. That is the point of it. It also means the second half of a step cannot run until you clear the first half's latch: `dry off` is written into 4a, 4b and 7c below, and step 6 turns the latch deliberately on. `status` prints `dry=` so you never have to guess which state you are in.

| step | do | proves |
| --- | --- | --- |
| 0 | Continuity before power: 12 V to every 5 V rail OPEN; relay COM-NO OPEN with the coil off; every GND common at the star; barrel plug centre +. Then on USB, before 12 V goes onto COM: `status` says `build=bringup`, `dry=0`, `contra=0` and the pump level you expect from the module you read. `build=bench` before the unattended run. | nothing is crossed, and the binary is the one you think it is |
| 1 | Board alone on USB: `i2c` sees 0x20 (expander), the LCD backpack at 0x27 or 0x3F (whichever your board is - note it on the rig), and 0x3C (OLED); 0x38 as well if the kit has the DHT20. | I2C, pull-ups, and that all three bus devices answer |
| 2 | Mux + one moisture sensor: `mux all` reads all 16 channels, the wired one moves when wetted. | select lines, ADC path |
| 3 | Halls on USB: screw (D3) and float (D5) follow a magnet; home changes through expander P4. | both pull-ups and the expander as an input |
| 4a | Relay DRY, no 12 V on COM: `status` first, to read the compiled pump level. `pump 2000` clicks; meter COM-NO closed while it holds, open after. COM-NO must ALSO stay open across a power cycle and across a `hang`-forced watchdog reset, not only across a `pump 2000`. The watchdog reset lands mid-dose, so it latches dry: `dry off` before 4b. | polarity of IN, the sketch's OFF level, and that the boot PFS write leaves D6 off through every reset |
| 4b | Still dry: press RESET mid-click -> contacts open. That reset latches dry too (`status` says `dry=1`): `dry off` before 4c. | R1 holds the OFF level |
| 4c | Still dry: pull the D6 jumper mid-click -> contacts open (no reset here, so no latch). Only now wire 12 V onto COM. | no hidden path to the coil |
| 5a | Float in the 'below the line' state -> `pump 2000` is refused. | the firmware interlock |
| 5b | Unplug the float hall mid-dose -> stops; meter S in that state (>= 4 V). Confirm `status` says `contra=0` afterwards: the float dropping mid-dose is the two sensors agreeing, not contradicting. | an open reads as 'not OK' (R2), and that agreement does not latch |
| 6 | `dry on` first: the cart moves, the pump is refused unconditionally while the plumbing is open. Move power to the barrel jack from the 12 V brick (USB carried steps 1-5; it will not carry the servo). Servo: `servo`, `home`, `goto`, then repeat with WiFi connected and the cart stalled against an end stop. `dry off` before 7a. | the buck carries stall + TX; a reset here means C1 is missing or too small |
| 7a | Bucket only: prime with `pump <ms> prime` - `prime` extends the no-flow window and caps the dose at 20 s, and removes no abort. Then `pump 2000` runs. | the pump loop |
| 7b | Pump a weighed 500 ml through outlet 1 counting pulses = ml/pulse; record the lowest flow that still pulses and set the no-flow timeout from it. | meter variant, calibration, floor |
| 7c | RESET mid-dose -> stops; `status` says `dry=1` and `last=resetmid`. `dry off`, then force a hang (`pump <ms> hang`) -> the WDT must reset the board and drop the pump inside its window; after that reset `status` must again say `dry=1` and `last=resetmid`. `dry off` before 7d. | the watchdog, now the ONLY thing between a hung sketch and a running pump, and that the latch survives a warm reset |
| 7d | Measure pump start and dead-head current; fix the F1 value. | fuse value |
| 7e | Flash the unattended binary: `status` says `build=bench` and `dry=0`, and none of `pump`, `cal`, `servo`, `home`, `goto` is a command (nor `hang` as a `pump` argument). Then start the 48-hour run. | the unattended binary is a different binary, with no console path to the pump or to the cart |

## Running the bench

Three things to know during the 48-hour run that `status` cannot tell you. They are requirements of the firmware spec (2.7, 2.9, 15.2), not advice, and the firmware's `AGENTS.md` carries the same three rules:

- **A power cycle after a latch silently rearms the rig.** The dry latch and the contradiction latch live in the firmware's `.noinit`, which survives a warm reset and does not survive a power cycle or a brown-out. Pulling the plug on a latched rig and plugging it back in clears the latch and lets the next backend command water. Until the backend keeps the durable half of the latch, the only safe way to end a latched session is to leave it latched and read `status`.
- **A `next` below about 60 s will visibly stutter while doses are live.** A dose blocks the board for up to 60 s and the network poll cannot run while it does, so a report interval shorter than a dose is an interval the board cannot keep. The reports are not lost; they are late, and the lateness is proportional to how much watering is happening.
- **After any power event, look for gaps in `readings`.** The boot salt covers a watchdog reset and the RESET button, not a brown-out or a power-cycle loop - those clear SRAM, so the boot counter restarts and two boots can collide on `(controller, t)` inside the backend's 300 s dedup window, which shows up as a missing row rather than as an error anywhere.

## Regenerate

```bash
make -C cad/wiring            # drawings (SVG + PNG at 150 dpi) and this README
make -C cad/wiring drawings   # draw.py -> overview, pump-driver, sensor-bus, power
make -C cad/wiring readme     # gen_readme.py -> README.md
```

Needs `uv`; it fetches schemdraw and matplotlib into an ephemeral environment. Facts live in `nets.py`, the look in `style.py`, one `draw_*.py` per drawing.

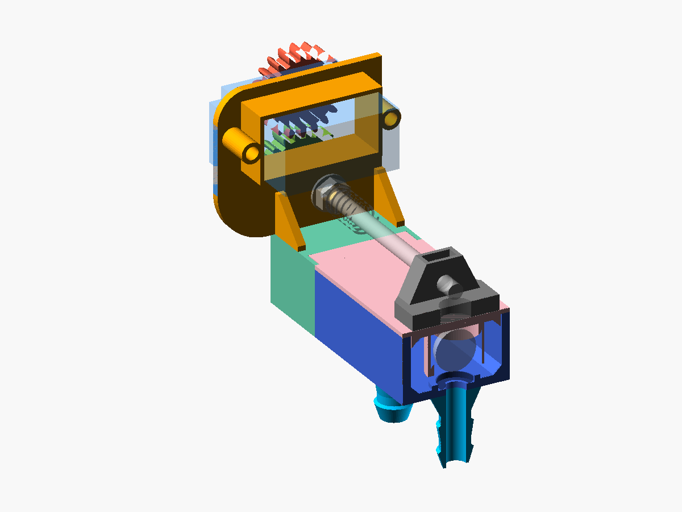
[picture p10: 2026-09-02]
manifold/renders/assembly_cart.png

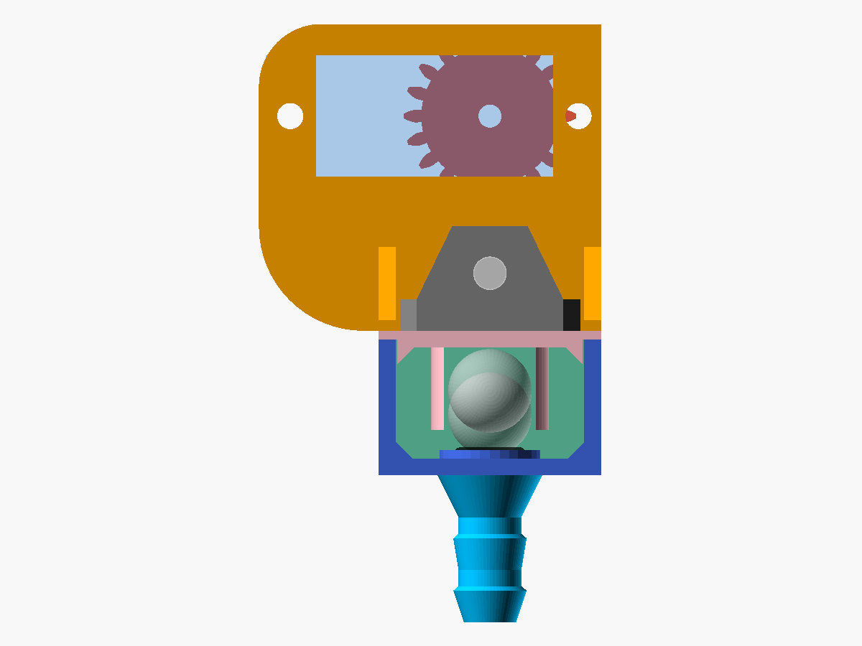
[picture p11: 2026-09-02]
manifold/renders/assembly_between.png

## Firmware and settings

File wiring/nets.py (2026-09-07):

"""One source of truth for the bench wiring: modules, every wire, tables, parts.

The drawings (draw_*.py) and the README (gen_readme.py) are both generated
from this file, so a pin changes here and nowhere else. Facts come from the
wiring brief (2026-09-02) and umbrella DECISIONS.md #5 and #7. Nothing in
here is firmware: the bench command set is a requirement on the bench sketch.

Net names (and their colours, see style.COLOURS): 12V, 5V_BOARD, GND,
SIGNAL, I2C, PUMP_SW (the pump's switched 12 V leg: NOT ground).

Revision 2026-09-03, after the bench feedback: no UBEC (the R4's own buck
feeds the servo), no 74HC00 and no MOSFET (a relay module switches the pump
and the interlock moves into firmware), the home hall moves onto the I2C
expander. See INTERLOCK_NOTES for what that costs.
"""

from __future__ import annotations

from dataclasses import dataclass, fields, is_dataclass
from typing import Any, Iterable, Sequence

DATE = "2026-09-03"

# Physical wire colour per net: what to reach for on the bench.
COLOUR_NAMES: dict[str, str] = {
    "12V": "red",
    "5V_BOARD": "orange",
    "GND": "black",
    "SIGNAL": "blue",
    "I2C": "green",
    "PUMP_SW": "purple",  # or red with purple tape: switched 12 V out of the relay, not GND
}

# ---------------------------------------------------------------- modules
# id -> (name on the drawings, status). Status: in hand | ASSUME (ordered,
# exact model unknown) | bench (rail, star point, perfboard we build).
MODULES: dict[str, tuple[str, str]] = {
    "UNO": ("Arduino UNO R4 WiFi", "in hand"),
    "PCF8575": ("PCF8575 I2C expander 0x20", "in hand"),
    "MUX1": ("CD74HC4067 mux MUX1", "in hand"),
    "MUX2": ("CD74HC4067 mux MUX2 (later)", "later"),
    "MOIST1": ("moisture 1 (capacitive)", "in hand"),
    "MOIST2": ("moisture 2 (capacitive)", "in hand"),
    "MOIST3": ("moisture 3 (capacitive)", "in hand"),
    "MOIST4": ("moisture 4 (capacitive)", "in hand"),
    "MOIST5": ("moisture 5 (capacitive)", "in hand"),
    "LDR": ("Sensor Kit light (LDR)", "in hand"),
    "DHT": ("Sensor Kit temp/humidity (DHT11)", "in hand"),
    "OLED": ("Sensor Kit OLED SSD1306 0x3C", "in hand"),
    "LCD": ("LCD1602 + PCF8574 backpack 0x27", "in hand"),
    "SERVO": ("SG90 continuous servo", "in hand"),
    "HALL_SCREW": ("WPSE313 hall: screw pulse", "in hand"),
    "HALL_HOME": ("WPSE313 hall: home", "in hand"),
    "HALL_FLOAT": ("WPSE313 hall: float (tank)", "in hand"),
    "FLOW": ("YF-S401 flow meter", "ASSUME"),
    "RELAY": ("1-channel relay module K1", "in hand"),
    "PERFBOARD": ("power board: F1, 12 V terminals, GND star", "bench"),
    "PUMP": ("12 V diaphragm pump", "ASSUME"),
    "BRICK": ("12 V >= 3 A brick", "ASSUME"),
    "RAIL5V": ("5V_BOARD rail (breadboard)", "bench"),
    "RAILGND": ("GND rail (breadboard)", "bench"),
    "STAR": ("GND star (power board)", "bench"),
}


def module_name(mid: str) -> str:
    return MODULES[mid][0]


# ---------------------------------------------------------------- wires
@dataclass(frozen=True)
class Wire:
    frm: str  # module id
    frm_pin: str  # silkscreen / lead name at that end
    to: str
    to_pin: str
    net: str  # key of COLOUR_NAMES
    signal: str = ""  # name printed on the wire in the drawings
    via: str = ""  # series or pull part on the way ("1 k series", "10 k pull-up")
    connector: str = ""
    cable: str = ""  # length / routing note
    later: bool = False  # expansion, drawn dashed, not on the bench

    @property
    def board_pin(self) -> str:
        """The UNO pin this wire lands on, or ''."""
        if self.frm == "UNO":
            return self.frm_pin
        if self.to == "UNO":
            return self.to_pin
        return ""

    @property
    def colour(self) -> str:
        return COLOUR_NAMES[self.net]

    def other_end(self, mid: str) -> tuple[str, str]:
        """(module id, pin) at the end that is not `mid`."""
        return (self.to, self.to_pin) if self.frm == mid else (self.frm, self.frm_pin)


_I2C_PULL = "ONE set of pull-ups for the whole bus: 4.7 k to 5V_BOARD (VERIFY each module; remove the rest)"
_HALL_CONN = "3-pin S / + (middle) / -"
_HALL_PULL = "10 k pull-up to 5V_BOARD at the breadboard"
_PH = "JST-PH 2.0 3-pin (VCC, GND, AOUT)"
_GROVE = "Grove 4-pin (VCC, GND, SIG, NC)"

WIRES: list[Wire] = [
    # -- UNO pins ------------------------------------------------------------
    Wire("UNO", "D2", "FLOW", "yellow (pulse)", "SIGNAL", "FLOW",
         via="1 k series at the board, 10 k pull-up to 5V_BOARD (R4)",
         connector="3-wire lead red / black / yellow",
         cable="<= 1 m; away from the servo lead; interrupt pin: pulses are counted, never muxed"),
    Wire("UNO", "D3", "HALL_SCREW", "S", "SIGNAL", "HALL_SCREW",
         via=_HALL_PULL, connector=_HALL_CONN,
         cable="<= 50 cm; hall fixed, magnet on the screw; interrupt pin: a missed edge is lost position"),
    Wire("UNO", "D5", "HALL_FLOAT", "S", "SIGNAL", "HALL_FLOAT",
         via="10 k pull-up to 5V_BOARD at the breadboard (R2)",
         connector=_HALL_CONN + " plug: the one pulled in bring-up 5b",
         cable="to the reservoir, <= 1 m; direct pin, NOT the expander: shortest path for the safety input"),
    Wire("UNO", "D6", "RELAY", "IN", "SIGNAL", "PUMP_EN",
         via="10 k to the module's OFF level (R1): pull-down if active-HIGH, pull-up to 5V_BOARD if active-LOW",
         connector="Dupont", cable="<= 30 cm; the jumper pulled in bring-up 4c"),
    Wire("UNO", "D7", "DHT", "SIG", "SIGNAL", "DHT_DATA",
         connector=_GROVE,
         cable="Grove 20-50 cm; direct pin: us-level one-wire timing cannot cross a mux or the expander. "
               "Free if the kit has the DHT20 (I2C)"),
    Wire("UNO", "D9", "SERVO", "orange (signal)", "SIGNAL", "SERVO_PWM",
         connector="JR 3-pin brown / red / orange",
         cable="servo lead ~25 cm; direct pin: a servo needs its 50 Hz train unbroken (PCA9685 to expand)"),
    Wire("UNO", "A0", "MUX1", "SIG", "SIGNAL", "MUX1_SIG",
         connector="header / Dupont", cable="<= 20 cm; analog, 14-bit"),
    Wire("UNO", "A4", "PCF8575", "SDA", "I2C", "SDA", via=_I2C_PULL,
         connector="header / Dupont", cable="<= 20 cm"),
    Wire("UNO", "A5", "PCF8575", "SCL", "I2C", "SCL", via=_I2C_PULL,
         connector="header / Dupont", cable="<= 20 cm"),
    Wire("UNO", "A4/A5", "OLED", "SDA / SCL", "I2C", "SDA + SCL", via=_I2C_PULL, connector=_GROVE,
         cable="Grove 20-50 cm; the same two wires as the expander: A4/A5 are a bus, not a pin each"),
    Wire("UNO", "A4/A5", "LCD", "SDA / SCL", "I2C", "SDA + SCL", via=_I2C_PULL,
         connector="header / Dupont",
         cable="<= 30 cm; shares the bus with the expander and the OLED"),
    Wire("UNO", "5V", "RAIL5V", "+", "5V_BOARD", "5V_BOARD",
         connector="header / Dupont",
         cable="<= 20 cm; OUTPUT only, never fed. The board's buck gives 1.2 A total from VIN: see POWER_BUDGET"),
    Wire("UNO", "GND", "STAR", "GND", "GND", "GND",
         connector="screw terminal", cable="<= 30 cm; the pump's 12 V return never passes here"),
    Wire("BRICK", "12V+", "UNO", "VIN (barrel)", "12V", "12V",
         via="1 A fuse F2, + leg only", connector="barrel 5.5/2.1 mm, centre +",
         cable="the servo and the relay coil come out of this: do NOT run them on USB power (500 mA port)"),
    # -- 5V_BOARD rail -> modules -------------------------------------------
    Wire("RAIL5V", "+", "MUX1", "VCC", "5V_BOARD", "5V_BOARD", via="100 nF at the module"),
    Wire("RAIL5V", "+", "PCF8575", "VCC", "5V_BOARD", "5V_BOARD", via="100 nF at the module"),
    Wire("RAIL5V", "+", "HALL_SCREW", "+ (middle)", "5V_BOARD", "5V_BOARD", connector=_HALL_CONN),
    Wire("RAIL5V", "+", "HALL_HOME", "+ (middle)", "5V_BOARD", "5V_BOARD", connector=_HALL_CONN),
    Wire("RAIL5V", "+", "HALL_FLOAT", "+ (middle)", "5V_BOARD", "5V_BOARD", connector=_HALL_CONN),
    Wire("RAIL5V", "+", "FLOW", "red", "5V_BOARD", "5V_BOARD",
         cable="5V_BOARD ONLY, never 12 V: the pulses swing to the supply"),
    Wire("RAIL5V", "+", "DHT", "VCC", "5V_BOARD", "5V_BOARD", connector=_GROVE),
    Wire("RAIL5V", "+", "LDR", "VCC", "5V_BOARD", "5V_BOARD", connector=_GROVE),
    Wire("RAIL5V", "+", "OLED", "VCC", "5V_BOARD", "5V_BOARD", connector=_GROVE),
    Wire("RAIL5V", "+", "LCD", "VCC", "5V_BOARD", "5V_BOARD", connector="Dupont",
         cable="the backlight is most of the ~60 mA the two screens draw"),
    *[Wire("RAIL5V", "+", f"MOIST{i}", "VCC", "5V_BOARD", "5V_BOARD", connector=_PH,
           cable="lead + extension <= 1.5 m") for i in range(1, 6)],
    Wire("RAIL5V", "+", "RELAY", "VCC", "5V_BOARD", "5V_BOARD", connector="Dupont",
         cable="coil ~80 mA (VERIFY); if the module has a JD-VCC jumper, leaving it fitted is what puts "
               "the coil on this rail"),
    Wire("RAIL5V", "+", "SERVO", "red", "5V_BOARD", "5V_BOARD", connector="JR 3-pin",
         cable="its OWN pair from the rail's feed point, plus 470-1000 uF and 100 nF AT THE SERVO PLUG: "
               "that cap, not the rail, is what stops a stall dip resetting the board"),
    # -- GND ----------------------------------------------------------------
    Wire("STAR", "GND", "RAILGND", "-", "GND", "GND", cable="one wire, star -> breadboard GND rail"),
    Wire("RAILGND", "-", "MUX1", "GND", "GND", "GND"),
    Wire("RAILGND", "-", "PCF8575", "GND", "GND", "GND"),
    Wire("RAILGND", "-", "HALL_SCREW", "-", "GND", "GND", connector=_HALL_CONN),
    Wire("RAILGND", "-", "HALL_HOME", "-", "GND", "GND", connector=_HALL_CONN),
    Wire("RAILGND", "-", "HALL_FLOAT", "-", "GND", "GND", connector=_HALL_CONN),
    Wire("RAILGND", "-", "FLOW", "black", "GND", "GND"),
    Wire("RAILGND", "-", "DHT", "GND", "GND", "GND", connector=_GROVE),
    Wire("RAILGND", "-", "LDR", "GND", "GND", "GND", connector=_GROVE),
    Wire("RAILGND", "-", "OLED", "GND", "GND", "GND", connector=_GROVE),
    Wire("RAILGND", "-", "LCD", "GND", "GND", "GND", connector="Dupont"),
    *[Wire("RAILGND", "-", f"MOIST{i}", "GND", "GND", "GND", connector=_PH) for i in range(1, 6)],
    Wire("RAILGND", "-", "RELAY", "GND", "GND", "GND", connector="Dupont", cable="coil return"),
    Wire("SERVO", "brown", "STAR", "GND", "GND", "GND", connector="JR 3-pin",
         cable="to the star, not the sensor rail: keeps the stall dip out of the ADC ground"),
    Wire("MUX1", "EN", "RAILGND", "-", "GND", "MUX1_EN",
         cable="EN tied LOW: mux always enabled (breakouts may pull EN down with 10 k)"),
    # -- analog into the mux ------------------------------------------------
    *[Wire(f"MOIST{i}", "AOUT", "MUX1", f"C{i - 1}", "SIGNAL", f"MOIST{i}", connector=_PH,
           cable="~10 k source; 0-3 V") for i in range(1, 6)],
    Wire("LDR", "SIG", "MUX1", "C5", "SIGNAL", "LIGHT", connector=_GROVE, cable="0-5 V"),
    # -- expander: mux select out, home hall in ------------------------------
    *[Wire("PCF8575", f"P{i}", "MUX1", f"S{i}", "SIGNAL", f"MUX_S{i}", cable="<= 20 cm")
      for i in range(4)],
    Wire("HALL_HOME", "S", "PCF8575", "P4", "SIGNAL", "HALL_HOME",
         via="10 k pull-up to 5V_BOARD at the breadboard (R3)", connector=_HALL_CONN,
         cable="<= 50 cm; a level, not a pulse train: the expander is fast enough (a 2-byte read is ~0.3 ms). "
               "Write P4 HIGH before reading it (quasi-bidirectional)"),
    # -- 12 V and the pump loop ---------------------------------------------
    Wire("BRICK", "12V+", "PERFBOARD", "12V_IN", "12V", "12V",
         via="T 3 A slow-blow F1, + leg only", connector="screw terminal", cable=">= 0.5 mm2"),
    Wire("PERFBOARD", "12V_OUT", "RELAY", "COM", "12V", "12V",
         connector="screw terminal", cable=">= 0.5 mm2; the relay switches the + leg"),
    Wire("RELAY", "NO", "PUMP", "+", "PUMP_SW", "PUMP+",
         connector="screw terminal", cable=">= 0.5 mm2; NO, not NC: no coil = no pump"),
    Wire("BRICK", "12V-", "STAR", "GND", "GND", "GND", connector="screw terminal", cable=">= 0.5 mm2"),
    Wire("PUMP", "-", "STAR", "GND", "GND", "GND",
         connector="screw terminal", cable=">= 0.5 mm2; straight to the star, never the board's GND pin"),
    # -- later: second mux, next manifolds (dashed) -------------------------
    *[Wire("PCF8575", f"P{i}", "MUX2", f"S{i}", "SIGNAL", f"MUX_S{i}", later=True,
           cable="select lines shared with MUX1") for i in range(4)],
    Wire("PCF8575", "P6", "MUX2", "EN", "SIGNAL", "MUX2_EN", later=True),
    Wire("MUX2", "SIG", "UNO", "A1", "SIGNAL", "MUX2_SIG", later=True),
]

# Board pins not wired on this bench, and what they are earmarked for.
BOARD_PINS_FREE: list[tuple[str, str]] = [
    ("D0 / D1", "serial: keep free"),
    ("D4", "HALL_SCREW manifold 2 (later; freed when the home hall moved to the expander)"),
    ("D8", "free"),
    ("D10", "HALL_SCREW manifold 3 (later)"),
    ("D11", "free"),
    ("D12", "SERVO_PWM manifold 2 (later)"),
    ("D13", "SERVO_PWM manifold 3 (later)"),
    ("A1", "MUX2 SIG (later)"),
    ("A2", "free (analog)"),
    ("A3", "free (analog)"),
]

# Per-manifold pin plan (manifold 1 is the bench; 2 and 3 are later).
MANIFOLD_PINS: list[dict[str, str]] = [
    {"manifold": "1 (bench)", "servo": "D9", "hall_screw": "D3", "hall_home": "P4 (expander)", "mux_sig": "A0 (MUX1)"},
    {"manifold": "2 (later)", "servo": "D12", "hall_screw": "D4", "hall_home": "P8 (expander)", "mux_sig": "A1 (MUX2)"},
    {"manifold": "3 (later)", "servo": "D13", "hall_screw": "D10", "hall_home": "P9 (expander)",
     "mux_sig": "A1 (MUX2, C6-C15)"},
]
MANIFOLD_NOTE = (
    "What scales where, by signal type, not by habit: analog and slow (moisture, light) on the mux, "
    "16 a piece; a level and slow (home hall, and the one float) on the expander or a spare pin; a "
    "counted pulse train (screw hall, flow meter) on an interrupt pin, because a mux is a switch and "
    "an edge missed while it sits on another channel is lost cart position. Past three manifolds, "
    "route the screw halls through a 74HC4051 into one interrupt pin (only one manifold moves at a "
    "time) and the servos onto a PCA9685 (16 channels of hardware PWM over I2C, its own 5 V supply) "
    "rather than spending a board pin each.")


def pin_map() -> list[Wire]:
    """The wires that land on a UNO pin, in board-pin order (bench first, later last)."""
    order = ["D2", "D3", "D5", "D6", "D7", "D9", "A0", "A1", "A4", "A5", "A4/A5",
             "5V", "GND", "VIN (barrel)"]
    rows = [w for w in WIRES if w.board_pin]
    return sorted(rows, key=lambda w: (w.later, order.index(w.board_pin)))


def wires_of(mid: str, include_later: bool = False) -> list[Wire]:
    """Every wire touching module `mid`."""
    return [w for w in WIRES if mid in (w.frm, w.to) and (include_later or not w.later)]


# ---------------------------------------------------------------- tables
MUX_CHANNELS: list[dict[str, str]] = [
    *[{"channel": f"C{i}", "source": f"moisture {i + 1} AOUT", "signal": f"MOIST{i + 1}",
       "note": "raw counts; the backend maps channel -> pot"} for i in range(5)],
    {"channel": "C5", "source": "Sensor Kit LDR SIG", "signal": "LIGHT", "note": "0-5 V"},
    *[{"channel": f"C{i}", "source": "open", "signal": "spare",
       "note": "next manifolds' pots; leave open"} for i in range(6, 16)],
]
MUX_NOTES = [
    "EN tied to GND (always enabled): some breakouts pull EN down with 10 k, which the expander cannot lift.",
    "Firmware: select, wait >= 1 ms, read twice, keep the second (10 k source + ~70 ohm switch into the ADC sample capacitor).",
    "100 nF across VCC/GND at the module.",
]

EXPANDER_PINS: list[dict[str, str]] = [
    *[{"pin": f"P{i}", "use": f"MUX1 S{i}", "note": "shared with MUX2 later"} for i in range(4)],
    {"pin": "P4", "use": "HALL_HOME manifold 1 (INPUT)", "note": "10 k pull-up (R3); write P4 HIGH before reading"},
    {"pin": "P5", "use": "spare", "note": "MUX1 EN is tied to GND on the board"},
    {"pin": "P6", "use": "MUX2 EN (later)", "note": "dashed on the drawing"},
    {"pin": "P7", "use": "spare", "note": ""},
    *[{"pin": f"P{i}", "use": "spare", "note": "manifold 2-3 home halls (input), P8 then P9"} for i in range(8, 16)],
    {"pin": "INT", "use": "not connected", "note": "the home hall is polled; nothing here needs an edge"},
]
EXPANDER_NOTES = [
    "Quasi-bidirectional: pins power up HIGH, source ~100 uA high, sink 25 mA low.",
    "An input pin must be written HIGH before it is read, and it needs a real 10 k pull-up: 100 uA is "
    "too weak to hold a line next to a pump.",
    "NEVER PUMP_EN or the servo on the expander (power-on HIGH would run them).",
    "A failed or timed-out I2C read is not a zero: the firmware must treat it as 'home unknown' and refuse to move or pump.",
    "Address 0x20 with A0-A2 low; 100 nF across VCC/GND.",
]

I2C_ADDRESSES: list[dict[str, str]] = [
    {"address": "0x20", "device": "PCF8575 expander", "note": "A0-A2 low; Wire (A4/A5, 5 V)"},
    {"address": "0x21-0x26", "device": "more PCF8575", "note": "later manifolds; 0x27 is the LCD backpack, not a spare"},
    {"address": "0x27", "device": "LCD1602 I2C backpack", "note": "PCF8574; VERIFY (some backpacks ship at 0x3F)"},
    {"address": "0x38", "device": "DHT20 temp/humidity", "note": "only if the kit has the DHT20 (Environment_I2C)"},
    {"address": "0x3C", "device": "SSD1306 OLED 128x64 (u8x8)", "note": "Sensor Kit"},
]
I2C_NOTES = [
    "Wire on A4/A5 is 5 V with NO on-board pull-ups: the bus needs exactly one set, 4.7 k to 5V_BOARD.",
    "THREE modules sit on this bus now (expander, OLED, LCD backpack) over roughly 1.3 m of cable, and all "
    "three commonly ship their own pull-ups. VERIFY each module and keep ONE set fitted: three 10 k sets in "
    "parallel land near 3.3 k, which eats the 3 mA a device may sink; a single 10 k over a run this long is "
    "marginal for the 100 kHz rise time. One 4.7 k pair, on one module, and remove or leave off the rest.",
    "The Qwiic connector is Wire1 at 3.3 V: not for these modules.",
    "Both screens sit on the same two wires as the expander that carries the mux select lines and the "
    "home hall. The bus that paints a screen is the bus that reads the cart's position, so neither "
    "screen is painted while D6 is asserted.",
    "Grep any library added to this bus for Wire.flush(): TwoWire::flush() (Wire.cpp:833) spins on "
    "bus_status with no timeout and no iteration bound, so one wedged transaction never returns and "
    "the watchdog is what ends the dose.",
]

# ---------------------------------------------------------------- perfboard
# The power board is now only F1, the two 12 V terminals and the star: the
# switching lives on the bought relay module.
PERFBOARD_TERMINALS: list[dict[str, str]] = [
    {"terminal": "12V_IN", "wire": "brick 12V+ via F1 (T 3 A slow-blow)", "net": "12V", "gauge": ">= 0.5 mm2"},
    {"terminal": "12V_OUT", "wire": "relay COM", "net": "12V", "gauge": ">= 0.5 mm2"},
    {"terminal": "GND (star)", "wire": "brick 12V-, pump -, servo brown, UNO GND, breadboard GND rail",
     "net": "GND", "gauge": ">= 0.5 mm2 for the 12 V returns"},
]

RELAY_TERMINALS: list[dict[str, str]] = [
    {"terminal": "VCC", "wire": "5V_BOARD rail", "net": "5V_BOARD", "gauge": "Dupont"},
    {"terminal": "GND", "wire": "breadboard GND rail", "net": "GND", "gauge": "Dupont"},
    {"terminal": "IN", "wire": "UNO D6, with R1 10 k to the module's OFF level", "net": "SIGNAL", "gauge": "Dupont"},
    {"terminal": "COM", "wire": "power board 12V_OUT (brick + leg, after F1)", "net": "12V", "gauge": ">= 0.5 mm2"},
    {"terminal": "NO", "wire": "pump +", "net": "PUMP_SW", "gauge": ">= 0.5 mm2"},
    {"terminal": "NC", "wire": "not connected", "net": "SIGNAL", "gauge": "-"},
]
RELAY_NOTES = [
    "READ THE MODULE before the first power-up: active-HIGH or active-LOW input, coil current, contact "
    "rating, and whether a JD-VCC jumper separates the coil supply from VCC.",
    "In the sketch, ONE PFS write carries direction and level together: R_IOPORT_PinCfg(NULL, "
    "g_pin_cfg[D6].pin, IOPORT_CFG_PORT_DIRECTION_OUTPUT | (OFF level is HIGH ? "
    "IOPORT_CFG_PORT_OUTPUT_HIGH : 0)). Never call pinMode on D6: on this core it would drive the pin "
    "LOW and discard the level you just set.",
    "Why, on this silicon: pinMode(pin, OUTPUT) is R_IOPORT_PinCfg(..., "
    "IOPORT_CFG_PORT_DIRECTION_OUTPUT) (cores/arduino/digital.cpp:12-14), which bottoms out in an "
    "unconditional whole-register write, PmnPFS = cfg (bsp_io.h:391-395). cfg is 0x4, and the level "
    "bit IOPORT_CFG_PORT_OUTPUT_HIGH is 0x1 (r_ioport_api.h:186) - a bit pinMode never sets. So "
    "pinMode(D6, OUTPUT) latches PODR = 0 and drives D6 LOW, discarding a preceding digitalWrite. On "
    "an active-LOW module the old level-then-direction recipe therefore asserted the pump at every "
    "boot, watchdog resets included.",
    "R1 (10 k) holds the OFF level while D6 is an input: at reset, during boot, and with the jumper pulled.",
    "NO, never NC: a de-energised coil must leave the pump unpowered.",
    "Never PWM the contacts. ~10^5 mechanical cycles is decades at a few doses a day; a switched-on-and-off "
    "duty cycle is not.",
    "Optional, for contact life: a 100 ohm + 100 nF snubber across COM/NO. Not needed on the bench.",
]
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

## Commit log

2026-09-02 AGENTS.md: the manifold is a lead screw with a magnet cart, not rotary
    🤖 Written by an agent on behalf of @jcanton
2026-09-02 Manifold in OpenSCAD with ball gates
    A parametric OpenSCAD 2021.01 rebuild of the FreeCAD assembly valveV2: ten printed parts,
    every dimension derived from params.scad under asserts, the inverted-nail gates replaced by
    8 mm balls on O-ring seats in cages on the lid, the gallery height derived from the lift that
    passes lift_factor times the outlet bore area, the gears outboard of the servo plate, the cart
    nut captured in a top-loading slot, every part printable flat with no supports. assembly.scad
    places everything with ghosts of the hardware and six section views; make stl png check.
    valveV2.FCStd and .step are kept as read-only reference.
    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
    [assembly.scad, cart.scad, end_cap.scad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]
2026-09-02 Bench wiring: four drawings, the pin map and the bring-up order
    Everything needed to wire one manifold with five pots on the bench: the UNO R4 WiFi, a
    CD74HC4067 mux behind a PCF8575 so more pots and manifolds bolt on without rewiring, the five
    moisture sensors, the Sensor Kit light and temperature modules, the servo and the two halls,
    the flow meter, and the pump on a MOSFET low-side driver whose gate only rises when the
    firmware asserts PUMP_EN and the float hall sees its magnet.
    nets.py holds every wire and every table; style.py the look; one draw_*.py per drawing; the
    README is generated. So a fact is changed in one place and the drawings and the README follow.
    The interlock fails dry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
    [nets.py]
2026-09-03 Bench wiring, revised to the parts in hand
    Feedback from the bench changed four things; the drawings, the pin map and the
    bring-up order follow.
    No UBEC. The R4's ISL854102 buck gives 1.2 A total from VIN, so the servo and
    the relay coil live on the board's own 5 V pin, which an R3's linear regulator
    could not have carried. Two conditions come with that: the board is fed from
    the barrel jack, not a USB port, once the servo moves, and C1 (470-1000 uF)
    sits at the servo's plug rather than at the board. One 5 V rail now, so the
    5V_SERVO net and the rules that kept it apart are gone.
    A relay module instead of the MOSFET and the 74HC00. A de-energised coil is an
    open contact, so reset, lost pow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
    [nets.py]
2026-09-03 The D6 boot recipe was wrong for this silicon, and the screens were never drawn
    The pin table told you to set the level and then call pinMode. On the RA4M1 with
    this core, pinMode(pin, OUTPUT) is a whole-PFS-register write that latches PODR = 0
    and drives the pin LOW, discarding the digitalWrite before it — so on an active-LOW
    relay module that recipe asserts the pump at every boot, watchdog resets included.
    Verified in the installed core (digital.cpp:12-14 into bsp_io.h:391-395, with
    IOPORT_CFG_PORT_OUTPUT_HIGH = 0x1 a bit pinMode never sets) rather than taken on
    trust. Replaced by one R_IOPORT_PinCfg carrying direction and level together, and
    "never call pinMode on D6".
    The two screens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
    [nets.py]
2026-09-05 wiring: the three running rules the bench owes, after the bring-up table
    The bench-sketch firmware's AGENTS.md carries three rules that are requirements
    of its spec (2.7, 2.9, 15.2), and the person standing at the bench for the
    48-hour run reads this README, not that file. So they live here too, as
    RUNNING_NOTES in nets.py rendered under "Running the bench" right after step 7e
    starts the run: a power cycle after a latch silently rearms the rig; a `next`
    below about 60 s stutters while doses are live; after any power event, look
    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
2026-09-05 wiring: the command table says what the firmware does
    Three rows corrected against firmware main (775af92), found by a read-only
    cross-check of nets.py against cli.cpp:
    - `servo` takes an absolute pulse width, 1000-2000 us, and refuses a sign;
    the table promised a signed offset.
    - `calib` (one fixed 10 s primed dose for 7b) and `noinit pattern` (the 7c'
    canary) exist in the bring-up binary and were not in the table at all.
    - `dry on|off` said bring-up 4c latches dry; 4c pulls a jumper, not the
    reset line, and _check() already listed only 4a, 4b and 7c.
    README regenerated with `make readme`.
    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
    [nets.py]
2026-09-06 wiring: the float is judged against the tank's measured size
    The running note said a float that never changes state across a refill
    is presumed dead. That presumed the refill flipped it, which a top-up of
    a not-yet-empty tank never does. The rule is now the one DECISIONS #30
    records: stuck at full is more than the tank holds pumped since the last
    refill with the float still full; dead is still empty minutes after a
    refill; the tank's size is what the meter counted, median of five, armed
    after two. README regenerated.
    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
    [nets.py]
